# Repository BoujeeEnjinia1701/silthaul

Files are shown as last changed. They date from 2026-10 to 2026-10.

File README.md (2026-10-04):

# SiltHaul

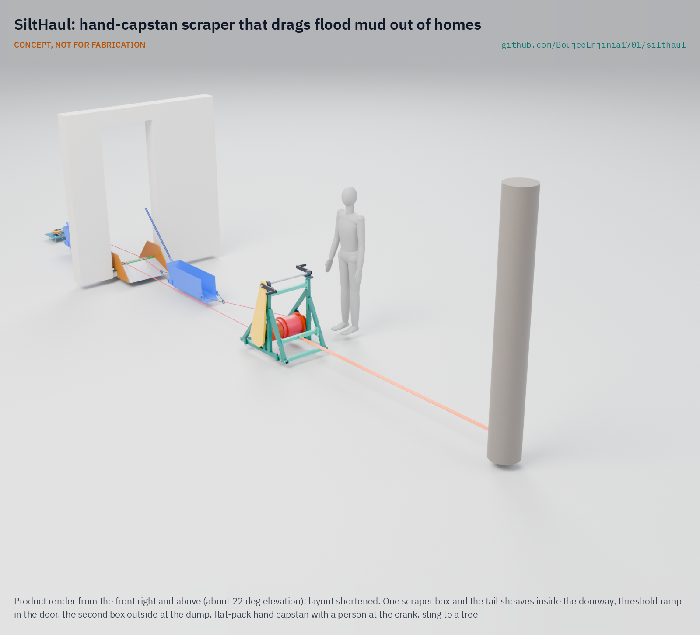
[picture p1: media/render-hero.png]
SiltHaul: hand-capstan scraper that drags flood mud out of homes


     

**Area:** Situational field hardware · **TRL:** 3 of 9 (proof of concept on paper; constructable design) · **Value-engineering target:** USD 2,000; estimated parts cost USD 887.50 · **Difficulty:** 3 of 5

Drags flood mud out of homes, lanes and drains with a hand-capstan scraper instead of shovels and buckets.

> CONCEPT, NOT FOR FABRICATION. SiltHaul is a TRL 3 design on paper: it has not been built or tested.

## Concept rationale

Mines solved a similar job a century ago with the slusher: a scraper dragged across the floor by rope and returned by a tail rope through a sheave at the far end ([Mining History Association](https://www.mininghistoryassociation.org/Journal/MHJ-v22-2015-Reynolds.pdf)). SiltHaul is a hand-powered slusher for flooded homes. A hand capstan is anchored outside the door, a tail sheave is fixed inside the room, and a rope loop runs between them to a scraper box. Crank one way and the box drags a load of mud out through the door; crank the other way and it returns for the next.

The point is to change who carries the weight. With shovels and buckets, people lift and carry every kilogram of mud. With SiltHaul, they load the box where it sits and the rope does the carrying. It uses no fuel and no power, fits through a doorway and packs into a car, so community groups and relief teams can bring it into lanes that machines cannot reach.

## Burning platform

After the 2018 Kerala floods, about 70,000 people joined a single clean-up drive in Kuttanad, aiming to clean about 100,000 buildings of silt, debris and mud across 16 panchayats ([Gulf News, 2018](https://gulfnews.com/world/asia/india/kerala-flood-70000-people-participate-in-massive-post-flood-clean-up-drive-in-kuttanad-1.2271770)). In the weeks that followed, at least 66 people died of leptospirosis ([Quartz, 2018](https://qz.com/india/1377755/after-kerala-floods-leptospirosis-has-killed-nearly-70-in-india)), and the state health department told everyone engaged in cleaning after the flood to take preventive medicine ([Mongabay, 2018](https://india.mongabay.com/2018/09/leptospirosis-outbreak-causes-concern-in-kerala-after-the-floods/)).

The pattern repeats wherever floods reach homes. In Valencia in 2024, thousands of volunteers self-organised to clear mud and debris after floods that killed at least 232 people ([Wikipedia](https://en.wikipedia.org/wiki/2024_Spanish_floods)). OSHA warns that flood clean-up workers risk back, knee and shoulder injuries from manual lifting and handling, and faces biological hazards from sewage and other contamination in floodwater ([OSHA](https://www.osha.gov/flood/response)).

## Where it could be used

### By industry

| Industry | Use |
| --- | --- |
| Disaster relief and humanitarian response | Mud clearance kits for volunteer and NGO clean-up teams |
| Municipal services | Clearing silted drains, culverts and narrow lanes without heavy plant |
| Civil protection and volunteer fire services | Pre-positioned flood recovery equipment |
| Housing and restoration contractors | Mucking out ground floors and basements where machines cannot enter |
| Agriculture | Clearing silt from farm buildings, sheds and small channels after floods |

### By country or region

| Country or region | Why it matters there |
| --- | --- |
| India | About 70,000 volunteers turned out to clean about 100,000 buildings in Kuttanad after the 2018 Kerala floods ([Gulf News, 2018](https://gulfnews.com/world/asia/india/kerala-flood-70000-people-participate-in-massive-post-flood-clean-up-drive-in-kuttanad-1.2271770)). |
| Pakistan | The 2022 floods affected 33 million people and caused USD 5.6 billion of damage to housing ([ReliefWeb, PDNA](https://reliefweb.int/report/pakistan/pakistan-floods-2022-post-disaster-needs-assessment)). |
| Spain | After the 2024 Valencia floods, thousands of volunteers self-organised to clean mud and debris from affected towns ([Wikipedia](https://en.wikipedia.org/wiki/2024_Spanish_floods)). |
| Germany | In the Ahr valley in 2021, about 3,000 of 4,200 buildings along the river were damaged, and clean-up was still running six months later ([deutschland.de](https://www.deutschland.de/en/topic/environment/catastrophic-flooding-in-germany-rebuilding-in-the-ahr-valley)). |

## What sparked the idea

The idea came from the scale of the 2018 Kerala clean-up. In Kuttanad, about 70,000 people, from as far as Kannur district, came together to clear silt and mud from about 100,000 buildings, and ministers warned rehabilitation could take six months to a year ([Gulf News, 2018](https://gulfnews.com/world/asia/india/kerala-flood-70000-people-participate-in-massive-post-flood-clean-up-drive-in-kuttanad-1.2271770)). That much human effort, with shovels and buckets, suggested that a simple tool which moved mud by rope rather than by arms could multiply what each volunteer can do.

## Problem

After a flood, homes, lanes and drains are left full of heavy, contaminated mud, and it is cleared almost entirely by hand with shovels and buckets. The work is slow, exhausting and puts people in long contact with dirty water and silt.

Full problem statement: [docs/01-problem.md](docs/01-problem.md)

## Concept

A scraper box hauled on a rope loop by a hand capstan anchored outside, with a tail sheave inside the room; workers crank the capstan to drag flood mud out of homes, lanes and drains instead of shoveling it into buckets.

Full design precis: [docs/02-concept.md](docs/02-concept.md) · Requirements: [docs/03-requirements.md](docs/03-requirements.md) · Calculations: [docs/04-calcs/01-sizing.md](docs/04-calcs/01-sizing.md) · Prototype build plan: [docs/05-build-plan.md](docs/05-build-plan.md) · Design decisions: [docs/06-design-decisions.md](docs/06-design-decisions.md) · [3D viewer](media/viewer.html)

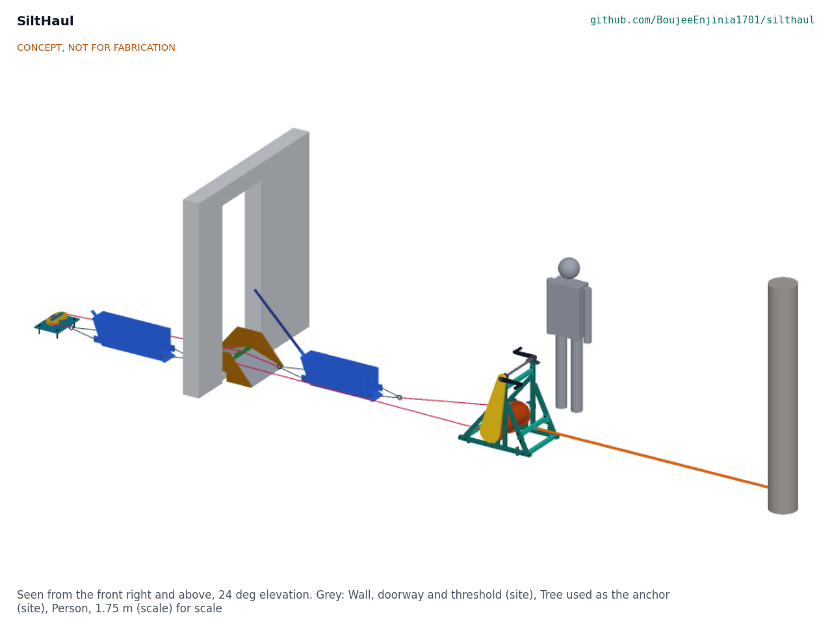
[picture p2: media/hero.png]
Concept: tail sheave block and box in the room, ramp in the doorway, hand capstan outside (layout shortened)


On paper (SLH-CAL-001): two boxes ride on the rope loop, so every stroke hauls a full 40 L box out while the other goes back to be filled. Two people at the cranks need 63 N each; a shear pin caps the rope tension at about 2.5 kN; the frame packs flat and the heaviest lift is 23.1 kg. It moves about 0.51 m³ an hour with a crew of four and a rest allowance, 0.57 times what the same crew moves with buckets, and nobody lifts or carries mud. Requirement R1, as Amish restated it (at least 0.5 times the bucket crew), is met on paper.

## Key components

- Hand capstan: a split winding drum, 4:1 chain drive, two cranks, shear pin and two ratchet wheels with pawls
- Outside anchor set: round sling to a tree or vehicle, four ground stakes
- Tail sheave block: two sheaves on a floor plate held by four M12 anchors
- Rope loop: 10 mm polyester pull rope and return rope
- Two scraper boxes: 210 mm wide, 40 L each, one on each rope, open toward the door, with bridles and a shared tipping bar
- Doorway rope guard: threshold ramp with a crest roller
- Stop signal and briefing card

## Building the prototype

The build plan takes a capable maker from stock steel tube, plate and sheet to a working prototype in thirteen illustrated steps, with a making sketch for each made part and close-ups of every joint that needs one. The flat-pack capstan frame, drum, two boxes, tail plate and ramp are welded or bolted from stock; the bearings, sprockets, chain, sheaves, anchors, rope and lifting gear are bought. It is a plan, not yet built; building and testing to it is TRL 4 work. See [docs/05-build-plan.md](docs/05-build-plan.md).

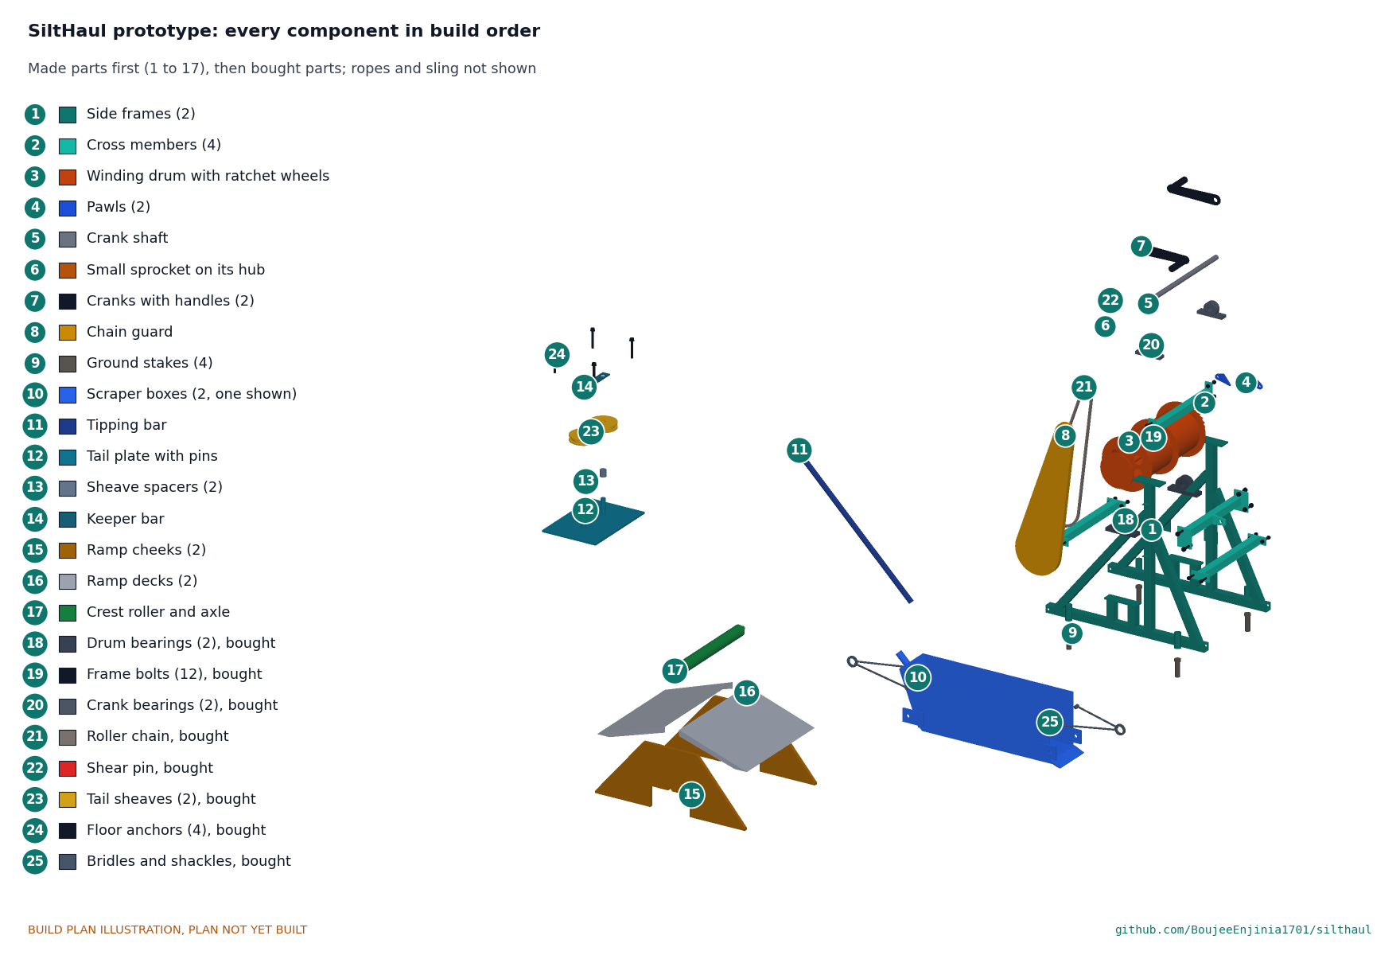
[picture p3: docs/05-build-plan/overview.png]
Every component of the prototype, pulled apart and numbered in build order


## Safety

> Published as an open engineering reference, not certified equipment. Users are responsible for their own risk assessment.
>
> This is a rope-and-anchor system under tension: a failed anchor or rope can whip. Nobody stands in the line of the rope or beside the sheave while cranking.
>
> All anchors, sheaves and ropes must be proof-loaded before use and inspected each day.
>
> The chain drive is fully guarded and a 4 mm shear pin limits the rope tension; never run without the guard or replace the pin with a stronger one. Choose a pawl before letting go of the cranks; two people tip the box, only with a pawl holding.
>
> The tail sheave block is anchored only to a sound concrete slab, never to walls or door frames; the capstan sling runs level or rises 10 degrees at most.
>
> Check the building for structural damage and switch off electricity before work starts.
>
> Flood mud may carry sewage and disease; users need boots, gloves and hygiene measures, and should follow local health advice.
>
> This design is published as an open engineering reference. It is not certified equipment. TRL 3 concept, not released for fabrication.

## Repository layout

| Folder | Contents |
| --- | --- |
| `docs/` | Problem, concept, requirements, calculations and design decisions |
| `cad/src/` | build123d Python source, the source of truth for all geometry |
| `cad/step/`, `cad/stl/` | Exported models for FreeCAD, other CAD tools and printing |
| `cad/drawings/` | 2D sketches and dimensioned drawings |
| `bom/` | Bill of materials |
| `electronics/` | KiCad schematics and PCB layouts |
| `firmware/` | Microcontroller code |
| `media/` | Renders, perspectives and photos |
| `build-log/` | Dated prototyping notes |

## Documentation

Controlled documents follow the portfolio [documentation standard](.kit/STANDARDS.md). Each carries a document ID (SLH-PRC-001 for the precis), a version and a revision history. Branded PDFs are built with `python .kit/render.py` and attached to GitHub Releases when a document is tagged, for example `SLH-PRC-001/v1.0`.

## Credits

Designed by Amish Chadha at Design Molecule Labs. See [CONTRIBUTORS.md](CONTRIBUTORS.md) for roles. To cite this design, use [CITATION.cff](CITATION.cff) (GitHub shows it as "Cite this repository").

AI assistance (Claude) was used to accelerate prototype documentation and first-pass research. Design direction and all decisions are Amish Chadha's, recorded in this repository's decision records (`docs/decisions/`).

## Licenses

- **Hardware** (CAD, drawings, BOM, electronics): [CERN-OHL-S v2](LICENSE)
- **Software** (firmware, scripts, notebooks): [MIT](LICENSE-SOFTWARE)

A project of the [Design Molecule](https://designmolecule.com) lab.

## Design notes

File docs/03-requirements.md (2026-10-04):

---
doc_id: SLH-REQ-001
title: SiltHaul requirements
project: SiltHaul
doc_type: Requirements
version: "0.5"
status: Draft
date: '2026-10-03'
author: Amish Chadha
license: CERN-OHL-S-2.0
revisions:
- version: "0.1"
  date: '2026-09-30'
  author: Amish Chadha
  change: Initial scaffold
- version: "0.2"
  date: '2026-10-03'
  author: Amish Chadha
  change: TRL 2 requirements with concept status; R11 overload limit and R12 load holding added (SLH-DDR-001)
- version: "0.3"
  date: '2026-10-03'
  author: Amish Chadha
  change: TRL 3 status from SLH-CAL-001 on the constructable design (SLH-DDR-002); R10 restated against the value-engineering target
- version: "0.4"
  date: '2026-10-03'
  author: Amish Chadha
  change: Amish's requirement decisions (SLH-DDR-003); R1 restated (no lifting or carrying of mud; at least 0.5 times the bucket crew) and met on paper with a second box on the return leg; R9 met on paper with a flat-pack frame; status rerun from SLH-CAL-001 v0.3
- version: "0.5"
  date: '2026-10-03'
  author: Amish Chadha
  change: "Amish's round-2 decision 2A (SLH-DDR-004): R9 restated as \"fits a small hatchback with the rear seats folded; heaviest part 25 kg or less\" and accepted as met on paper"
---

# SiltHaul requirements

Eleven of the twelve requirements are met on paper or by design, one (R8, setup time, now estimated at the 20 min limit) can only be verified by a timed trial, and none is reported not met (SLH-CAL-001 v0.4, Table 3). In round 2 (2026-10-03) Amish agreed with the recommendation on R9 (2A of SLH-DDR-004): "i agree with all the 46 recommendations you provided. please proceed." R9 is restated as "fits a small hatchback with the rear seats folded; heaviest part 25 kg or less". On 2026-10-03 Amish chose option A on every requirement decision put to him ("1A 2A 3A 4A 5A 6A 7A 8A 9A 10A 11A"), which for SiltHaul meant two changes (SLH-DDR-003). Under 2A, R1 is restated as "no lifting or carrying of mud; output at least 0.5 times the same crew with shovels and buckets", and a second box rides on the return leg so the rope loop carries mud out on both strokes: about 0.51 m³ an hour with rest, a ratio of 0.57. Under 7A, the frame is a bolted flat-pack frame so the kit fits a small car boot, with the 25 kg heaviest-part limit kept. R11 and R12 were added at TRL 2 under Amish's pre-approval of 2026-10-03 (SLH-DDR-001), because the anchors and rope can only be sized on a known maximum rope tension, and a hand-cranked load must hold when the handles are let go. "Met on paper" means shown by calculation, not by test.

> **Safety:** SiltHaul is a rope-and-anchor system under tension with a hand-cranked chain drive. R6, R7, R11 and R12 are its safety requirements; they are checked on paper only and must be proved by proof-load tests before anyone uses the kit (SLH-BLD-001, section 6).

Table 1. Requirements and status at TRL 3

| ID | Requirement | Target | Verification (TRL 3 or later) | Status (SLH-CAL-001) |
| --- | --- | --- | --- | --- |
| R1 | Mud moved per hour by a crew of four | No lifting or carrying of mud; output at least 0.5 times that of the same crew with shovels and buckets (estimate) | Side-by-side timed trial on a test bed of wet silt | Met on paper: 0.51 against 0.90 m³/h (ratio 0.57); loaders push mud in over the lip; nobody lifts or carries it |
| R2 | Crank handle force at full box | 150 N (34 lbf) or less per person with two people at the cranks | Spring balance at the handle during trial | Met on paper: 63 N each at 1,000 N (126 N for one person); 61 N each at the 970 N stroke estimate |
| R3 | Scraper box capacity | About 40 L (10 US gal) of wet mud per trip | Measured fill on test bed | Met by design: 40.3 L in each of the two boxes at a 245 mm fill |
| R4 | Fits through a doorway | Box, tail block and ramp pass a 0.7 m (28 in) opening, with the return leg beside the box | Fit test | Met by design: each box 258 mm over the shackles; the boxes pass 42 mm apart and cross the ramp 26 mm inside its cheeks; ramp 646 mm |
| R5 | Working length | Up to 15 m (49 ft) from tail sheave to capstan | Trial at full length | Met by design: 12 m of travel on each drum half; capstan at least 6 m from the door |
| R6 | Rope and anchor strength | Minimum break strength at least 5 times the working pull, and at least 5 times the R11 limit for the rope and chain | CalRig proof-load test of each anchor type | Met on paper: rope 18 times working, 5.4 at the limit; chain 5.0 |
| R7 | Tail anchor independent of walls | Holds the R11 limit on both legs on a bare concrete floor with no wall contact | Pull test on the anchored tail block | Met on paper on a sound slab: 0.45 of recommended anchor loads |
| R8 | Setup time | Three people set up in 20 min or less | Timed trial | Not verifiable at TRL 3: about 20 min estimated, at the limit (bolting the frame and shackling two boxes add 4 min) |
| R9 | Portability | Kit fits a small hatchback with the rear seats folded; heaviest part 25 kg or less (25 kg is 55 lb) | Weigh and pack test | Met on paper, as restated by Amish (2A, round 2): heaviest lift 23.1 kg (drum with bearings); flat-pack frame, largest piece 890 x 814 x 83 mm; kit about 454 L packed against a 594 L small car boot |
| R10 | Cost | Prototype parts at or under the USD 2,000 value-engineering target (a hypothetical control target) | Costed bill of materials | Met on paper, within the target: USD 1,055.60 (USD 944.40 under) |
| R11 | Overload limit | Rope tension limited to 3,000 N whatever force the crew applies | Shear pin release test on the capstan | Met on paper: shear pin releases at 2,451 N (1,961 to 2,941 N) |
| R12 | Holds when let go | The drum holds the load in either direction when the cranks are released | Release test at working pull | Met by design: two ratchet wheels and pawls on the drum shaft |

## Requirements at risk or not met

None is reported not met. Two results are close to their limits and are watched at TRL 4:

- **R1.** The ratio of 0.57 rests on estimated loading, dumping and bucket rates; a timed trial settles it. The restatement is Amish's (2A, 2026-10-03): "no lifting or carrying of mud; output at least 0.5 times the same crew with shovels and buckets".
- **R8.** About 20 min with three people, at the limit, now that the frame is bolted together on site and two boxes are shackled.
- **R9.** Accepted by Amish with the rear seats folded (round 2, 2A, 2026-10-03: "i agree with all the 46 recommendations you provided. please proceed."), and restated as "fits a small hatchback with the rear seats folded; heaviest part 25 kg or less". With the seats up the 890 x 814 mm side frames do not lie flat in a typical small boot; that is no longer an open question.

## Assumptions

- Most flood mud is fluid enough to be scraped and dragged, not dug; very stiff or deep deposits may still need shovels first.
- The building has a sound concrete slab at least 100 mm thick for the tail block anchors; where it does not, SiltHaul is not used in that room.
- Volunteers accept a short briefing on rope safety.
- "A small hatchback with the rear seats folded" is taken as a small hatchback's load space with the rear seats folded: 1,250 mm long, 950 mm wide and 500 mm high (about 594 L).
- Loaders push or rake mud into the box over its lip at floor level; the box is 305 mm tall, so shovelling over the side is possible but not needed.
- A safe dump point exists outside within rope reach, and an anchor point (a sound tree or a parked vehicle) exists behind the capstan.

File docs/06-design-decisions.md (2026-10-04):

---
doc_id: SLH-DEC-001
title: SiltHaul design decisions register
project: SiltHaul
doc_type: Design decisions register
version: "0.3"
status: Draft
date: '2026-10-03'
author: Amish Chadha
license: CERN-OHL-S-2.0
revisions:
- version: "0.1"
  date: '2026-10-03'
  author: Amish Chadha
  change: Register opened; every decision made under Amish's pre-approval of 2026-10-03
- version: "0.2"
  date: '2026-10-03'
  author: Amish Chadha
  change: Amish's requirement decisions 2A and 7A recorded (SLH-DDR-003); boot reading for R9 opened for Amish
- version: "0.3"
  date: '2026-10-03'
  author: Amish Chadha
  change: "Open decision 1 decided (round 2, 2A) and recorded as SLH-DDR-004; no open decisions"
---

# SiltHaul design decisions register

Every design decision still to be made, and every decision made, in one place. Each decision is argued in full in its decision record under `docs/decisions/`; this register is the index Amish works from. The build plan (`docs/05-build-plan.md`) describes the design as it stands and does not list decisions.

> **Safety:** Several decisions below set SiltHaul's safety case (overload limit, holding, anchors, dumping). Each took the conservative option; the evidence that would relax it is in SLH-DDR-001, Table 1.

## Open decisions

None. Open decision 1 (what "fits a small car boot" means) was decided by Amish on 2026-10-03: the rear seats folded; see Decisions made and SLH-DDR-004.

## To confirm when parts are bought

| # | What to confirm | Why it matters | Source |
| --- | --- | --- | --- |
| 1 | Release load of the shear pins from the bar actually bought | The 4 mm pin is sized on 240 MPa shear; a stronger bar raises the overload limit above 3,000 N | SLH-CAL-001, F; R11 |
| 2 | Recommended loads of the M12 wedge anchor bought, in the concrete grade expected | The tail block check uses 4 kN tension and 6 kN shear | SLH-CAL-001, I; R7 |
| 3 | Rope breaking strength and splice efficiency of the rope bought | Factor 5.4 at the limit assumes 18 kN and 90 % at the splice | SLH-CAL-001, G; R6 |
| 4 | Sheave bore and rating | Pins are 25 mm; the sheaves must be rated at least 1,000 kg | BOM line 14 |
| 5 | Bearing centre heights and bolt pitches | The pads and top plates are drilled to UCP206 and UCP205 catalogue sizes | SLH-DWG-101 |
| 6 | Sprocket bores and the 12-tooth sprocket's fit on the 36 mm hub | Sets the hub and the line-up with the 48-tooth wheel | SLH-DWG-104 |

## Value engineering

Value-engineering target: USD 2,000 (a hypothetical control target, not a limit). Estimated cost of the constructable design: USD 1,055.60 (USD 944.40 under the target). Main cost drivers and savings worth trying:

- The two boxes (USD 160) and the winding drum (USD 98) are the largest made parts; the rope (USD 80.60), the ramp (USD 73) and the frame (USD 72) follow.
- Bought lifting gear (sling, shackles, two bridle sets, USD 164) is kept at rated, traceable grades because it carries the safety case.
- Savings worth trying: a drum from a scrap gas cylinder or pipe offcut of the same diameter; a timber ramp with a steel wear strip; buying rope with factory eye splices in bulk.

## Decisions made

| Date | Decision | Decided by | Record |
| --- | --- | --- | --- |
| 2026-10-03 | Split winding drum in place of a friction capstan; 4:1 chain drive with two cranks | Amish: "I pre-approve the batch runs along with any recommendations you come up with." | SLH-DDR-001, items 1, 2 |
| 2026-10-03 | Shear pin limits rope tension to about 2.5 kN; all parts sized on 3,000 N; requirement R11 added | Amish: "I pre-approve the batch runs along with any recommendations you come up with." | SLH-DDR-001, item 3 |
| 2026-10-03 | Two opposite ratchet wheels and pawls on the drum shaft; requirement R12 added | Amish: "I pre-approve the batch runs along with any recommendations you come up with." | SLH-DDR-001, item 4 |
| 2026-10-03 | Tail block on four drilled floor anchors only, never walls or door frames | Amish: "I pre-approve the batch runs along with any recommendations you come up with." | SLH-DDR-001, item 5 |
| 2026-10-03 | Capstan anchored by a round sling to a tree or vehicle, level or rising 10 degrees at most; stakes only against skating | Amish: "I pre-approve the batch runs along with any recommendations you come up with." | SLH-DDR-001, item 6 |
| 2026-10-03 | 10 mm polyester double braid, 18 kN | Amish: "I pre-approve the batch runs along with any recommendations you come up with." | SLH-DDR-001, item 7 |
| 2026-10-03 | Box open toward the door, sloped back, forward tipping; two people on the tipping bar | Amish: "I pre-approve the batch runs along with any recommendations you come up with." | SLH-DDR-001, items 8, 9 |
| 2026-10-03 | Capstan at least 6 m beyond the door | Amish: "I pre-approve the batch runs along with any recommendations you come up with." | SLH-DDR-001, item 10 |
| 2026-10-03 | First co-design candidate to approach: Kerala State Disaster Management Authority (not agreed) | Amish: "I pre-approve the batch runs along with any recommendations you come up with." | SLH-DDR-001, item 11 |
| 2026-10-03 | SiltHaul capstan recorded as the candidate common block for SaltDrag; CalRig as the first candidate proof-load rig | Amish: "I pre-approve the batch runs along with any recommendations you come up with." | SLH-DDR-001, item 12 |
| 2026-10-03 | `budget_usd` kept at 2,000 as a value-engineering target | Amish: "I also accept any cost overruns or variations from the assumed scope cost." | SLH-DDR-001, item 13 |
| 2026-10-03 | R1 kept as the trial target and reported not met on paper (superseded by 2A below) | Amish: "I pre-approve the batch runs along with any recommendations you come up with." | SLH-DDR-001, Consequences |
| 2026-10-03 | Design for construction: the thirteen changes of SLH-DDR-002 | Amish: "I pre-approve the batch runs along with any recommendations you come up with." | SLH-DDR-002 |
| 2026-10-03 | Appearance model additions for renders: wound rope on the drum, stakes above ground only, context wall, tree and mannequin | Amish: "I pre-approve the batch runs along with any recommendations you come up with." | docs/REVIEW.md, TRL 3 |
| 2026-10-03 | 2A: second box on the return leg so the rope loop carries mud both ways; R1 restated as "no lifting or carrying of mud; output at least 0.5 times the same crew with shovels and buckets" (now 0.57, met on paper) | Amish: "1A 2A 3A 4A 5A 6A 7A 8A 9A 10A 11A" | SLH-DDR-003, items 1 to 5 |
| 2026-10-03 | 7A: bolted flat-pack frame (two welded side frames, four bolted cross members) that fits a small car boot, keeping the 25 kg heaviest-part limit (heaviest lift 23.1 kg) | Amish: "1A 2A 3A 4A 5A 6A 7A 8A 9A 10A 11A" | SLH-DDR-003, items 6 to 8 |
| 2026-10-03 | 2A (round 2): R9 accepted with the rear seats folded and restated as "fits a small hatchback with the rear seats folded; heaviest part 25 kg or less"; met on paper (heaviest lift 23.1 kg; kit about 454 L in 594 L). No design change | Amish: "i agree with all the 46 recommendations you provided. please proceed." | SLH-DDR-004 |

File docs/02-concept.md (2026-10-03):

---
doc_id: SLH-PRC-001
title: SiltHaul design precis
project: SiltHaul
doc_type: Precis
version: "0.3"
status: Draft
date: '2026-10-03'
author: Amish Chadha
license: CERN-OHL-S-2.0
revisions:
- version: "0.1"
  date: '2026-09-30'
  author: Amish Chadha
  change: Initial scaffold
- version: "0.2"
  date: '2026-10-03'
  author: Amish Chadha
  change: TRL 2 precis; how it works, components, first-order numbers, key design choices (SLH-DDR-001), safety
- version: "0.3"
  date: '2026-10-03'
  author: Amish Chadha
  change: TRL 3 figures from SLH-CAL-001 and the constructable design (SLH-DDR-002); split winding drum, shear pin, two-sheave tail block, ramp
---

# SiltHaul design precis

Drags flood mud out of homes, lanes and drains with a hand-capstan scraper instead of shovels and buckets.

Figure 1. SiltHaul in use, layout shortened

*Figure 1. Concept render: tail sheave block and scraper box in the room, ramp in the doorway, hand capstan outside with a sling to a tree (layout shortened).*

## Summary

SiltHaul is a hand-powered slusher for flooded buildings. Two steel scraper boxes, each 210 mm wide and holding about 40 L, are tied into a rope loop that runs from a hand capstan outside, through the doorway, round a tail sheave block anchored to the floor at the far end of the room, and back. Cranking one way drags one loaded box out through the door to a dump point while the other comes back empty; cranking the other way swaps them, so mud goes out on every stroke (SLH-DDR-003). Two people at the cranks need 63 N each; nobody lifts or carries mud out of the building. The design is constructable, its frame packs flat, its parts cost about USD 1,056 against a USD 2,000 value-engineering target, and its heaviest lift is 23.1 kg. On paper it moves about 0.51 m³ an hour with a crew of four and a rest allowance, 0.57 times a bucket crew (SLH-CAL-001).

## How it works

1. **Set up.** The capstan stands outside, at least 6 m beyond the door and in line with it, held back by a round sling to a tree or a parked vehicle and kept from skating by four stakes. The tail sheave block is bolted to the concrete floor at the far end of the room with four M12 anchors. A ramp straddles the threshold.
2. **The loop.** The pull rope runs from the lower side of the drum's pull half, over the ramp roller, to the box's front bridle. The return rope runs from the box's rear bridle to the tail block, round its two sheaves and back beside the box, 300 mm to one side, over the ramp roller to the top of the drum's return half.
3. **Haul.** Cranking winds the pull rope onto one half of the drum while the other half pays out the return rope at the same rate, so the loop stays the same length. The box's open front, which faces the door, scoops mud as it goes; workers also shovel or push mud into it.
4. **Dump.** The box stops at a dump point outside. A pawl holds the drum. Two people lift the loose tipping bar, which drops into a socket on the back, and the box rolls forward over its lip and empties.
5. **Return.** The other pawl is chosen and the cranks turned the other way. The sloped back rides over the mud as the empty box is pulled back.

## Main components

*Table 1. Components (numbers are BOM lines).*

| # | Component | What it is |
| --- | --- | --- |
| 1 | Capstan frame | Flat-pack, 40 mm square tube: two welded side frames (890 x 814 mm, 9.2 and 9.6 kg) with bearing pads, stake tubes and pawl brackets, joined by four bolted cross members including an anchor bar and eye at drum height |
| 2 | Winding drum | 219.1 mm tube in two halves of 21 turns each, on a 30 mm shaft, with a 48-tooth sprocket and two opposite ratchet wheels; 19.0 kg |
| 3, 4 | Bearings | UCP206 pillow blocks for the drum, UCP205 for the crank shaft |
| 5 | Crank shaft and cranks | 25 mm shaft 850 mm up, two 250 mm cranks set 180 degrees apart |
| 6, 7 | Chain drive | ISO 08B-1 chain, 12 to 48 teeth, 4:1 |
| 8 | Pawls | Two, one for each direction |
| 9 | Chain guard | Closed 1.5 mm sheet guard round the chain and sprockets |
| 10 | Shear pin | 4 mm S235 pin in the small sprocket hub; limits rope tension to about 2.5 kN |
| 11, 12 | Outside anchor set | Four stakes and a 2,000 kg round sling with shackles |
| 13 to 15 | Tail sheave block | 10 mm floor plate with two 125 mm sheaves on 25 mm pins, a keeper bar and four M12 floor anchors |
| 16 | Ropes | 10 mm polyester double braid, 18 kN: a 17 m pull rope and a 38 m return rope |
| 17, 18, 20 | Scraper box | 2 mm steel box with a bevelled lip, skids, sloped back, bridle lugs, bridles and a loose tipping bar |
| 19 | Doorway ramp | Plywood cheeks, steel decks and a crest roller; fits 0.7 m doors and 110 mm thresholds |
| 22 | Stop signal and briefing card | Hand signals, whistles and the stop rule |

## Numbers from the TRL 3 calculations

*Table 2. Key figures (SLH-CAL-001).*

| Quantity | Value |
| --- | --- |
| Full box | 40.3 L, 86 kg with mud at 1.7 kg/L; two boxes |
| Haul pull | 970 N estimated for a full box out and the empty one back; 1,000 N working pull |
| Crank force | 63 N each with two people; 126 N for one |
| Rope speed | 5.4 m/min |
| Stroke over 11 m | 3.54 min; 17 strokes and 0.68 m³ an hour (0.51 with rest) |
| Overload limit | Shear pin releases at about 2,450 N; all parts sized on 3,000 N |
| Rope | Factor 18 on the working pull, 5.4 on the limit |
| Tail block | 0.45 of recommended anchor loads at the limit |
| Heaviest lift | Drum with bearings 23.1 kg; box 16.1 kg |
| Cost | Value-engineering target: USD 2,000. Estimated cost of the constructable design: USD 1,055.60 (USD 944.40 under the target) |

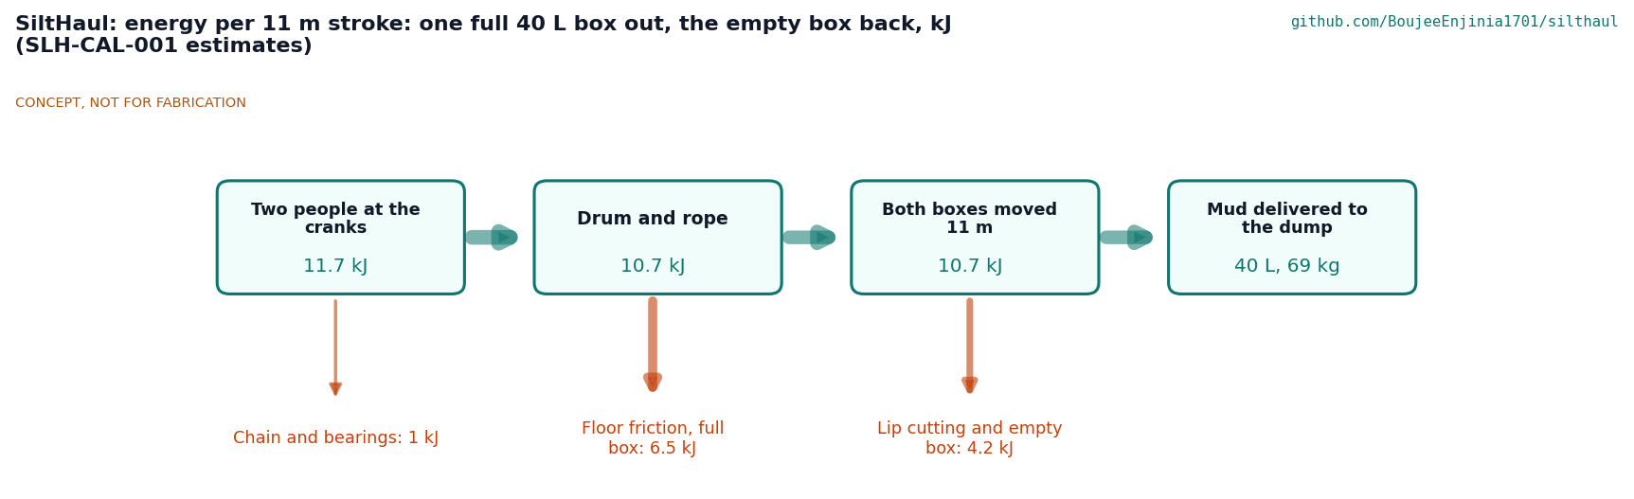
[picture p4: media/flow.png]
Figure 2. Energy per haul


*Figure 2. Energy for one 11 m haul of a full box (estimates): most of what the crank crew puts in goes to dragging the box over the floor.*

## Key design choices

All decided on 2026-10-03 under Amish's pre-approval (SLH-DDR-001 and SLH-DDR-002):

- **Split winding drum, not a friction capstan.** A loop on a friction drum needs a pretension of about half the pull and its turns walk along the drum. A drum whose halves wind and unwind together cannot slip and keeps the loop length constant.
- **Overload limit by shear pin.** Without it a jammed box and two people heaving could put 6.4 kN into the rope. With it every part is sized on 3,000 N.
- **Two ratchet wheels on the drum shaft.** The drum is held in either direction, even if the chain or pin fails.
- **A box on each leg.** Two boxes 210 mm wide on lines 300 mm apart pass each other in the room and both cross the ramp in a 0.7 m door, so mud goes out on every stroke (SLH-DDR-003).
- **Open front facing the door.** The box scoops on the way out and keeps its load against its back; it tips forward over its lip at the dump, like a Fresno scraper.
- **Tail block on drilled floor anchors only.** No reliance on walls or door frames; a room without a sound slab is not worked with SiltHaul.
- **Sling at drum height.** The anchor eye is 200 mm up so the rope and the sling pull in line and the capstan cannot tip.

## Patent design-arounds

From the preliminary patent, trademark and prior-art screen (not legal advice):

- Slusher patents US2588657A and US3532170A have expired and are free prior art; the Fresno scraper's forward-tipping bowl is nineteenth-century prior art.
- WO2017216731A1 (Sulzer scraper winch) is shown as ceased on Google Patents; a South African family member (ZA201808475B) is listed and should be confirmed before release. SiltHaul uses a hand-cranked split drum, not motor-driven drums.
- Watch item from the preliminary screen: tail-sheave anchor on weak, wet walls. The tail block has its own floor anchors and never bears on a wall.

## Relationship to other lab projects

- **Hand capstan common block.** SiltHaul's capstan is recorded as the candidate common block for SaltDrag; SaltDrag is checked against it when it reaches TRL 3 (not edited here).
- **CalRig.** The first candidate rig for the proof loads of the anchors, rope and capstan.

## Safety

> **Safety:** Published as an open engineering reference, not certified equipment. Users are responsible for their own risk assessment.
>
> **Rope under tension.** A failed anchor, shackle or rope can whip. Nobody stands in the line of a rope, inside the loop, or beside a sheave or the ramp while the cranks turn. The shear pin limits rope tension to about 2.5 kN; never replace it with a stronger pin or a bolt.
>
> **Moving machinery.** The chain and sprockets are fully guarded; never turn the cranks with the guard off. Keep hands clear of the drum and rope where it winds on. Choose the pawl before letting go of the cranks.
>
> **Anchors.** Every anchor, the rope and the capstan are proof-loaded before first use and the rope, splices, shackles and anchors are inspected each day. The tail block is used only on a sound concrete slab; the sling runs level or rises 10 degrees at most.
>
> **Dumping.** Two people lift the tipping bar, only when the cranks are stopped and a pawl is holding.
>
> **The building and the mud.** Check the building for structural damage and switch off electricity before work starts. Flood mud may carry sewage and disease; users need boots, gloves and hygiene measures, and should follow local health advice.
>
> **Stop rule.** One signaller, a whistle and the card's hand signals. One blast stops the cranks; nobody enters the rope area until the signaller says so.

## Open questions

None for the design. Questions about mud, floors and people are for the first trials: how the box fills and drags in liquid slurry and stiff clay, how often the slab is sound enough for the tail anchors, and the real bucket-crew rate for R1.

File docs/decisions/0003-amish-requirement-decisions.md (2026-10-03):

---
doc_id: SLH-DDR-003
title: SiltHaul second box on the return leg and flat-pack frame
project: SiltHaul
doc_type: Design decision record
version: "0.1"
status: Draft
date: '2026-10-03'
author: Amish Chadha
license: CERN-OHL-S-2.0
revisions:
- version: "0.1"
  date: '2026-10-03'
  author: Amish Chadha
  change: Amish's requirement decisions 2A (R1) and 7A (R9) carried into the constructable design
---

# 0003: Second box on the return leg and flat-pack frame

- **Date:** 2026-10-03
- **Status:** accepted

## Context

At TRL 3 (SLH-CAL-001 v0.2) SiltHaul missed R1, output, by a wide margin (0.32 m³ an hour, a ratio of 0.36 to a bucket crew against a target of 2), and R9, portability, was at risk because the welded frame, 890 x 663 x 814 mm, needed an estate car or small pickup. Both fixes change what the product is, so they were put to Amish as requirement decisions. On 2026-10-03 Amish chose option A on every decision put to him: "1A 2A 3A 4A 5A 6A 7A 8A 9A 10A 11A". For SiltHaul:

- **2A (R1).** Add a second box on the return run so the rope loop carries mud both ways; restate R1 as "no lifting or carrying of mud; output at least 0.5 times the same crew with shovels and buckets".
- **7A (R9).** Redesign the frame as a bolted flat-pack frame that fits a small car boot, keeping the 25 kg heaviest-part limit.

## Options considered

For 2A the open question was how two boxes fit through a 0.7 m door (R4) with their rope lines 300 mm apart, the spacing the drum and ramp already set.

| Option | Result | Chosen |
| --- | --- | --- |
| Two 446 mm boxes, lines moved about 540 mm apart | Ramp and door about 1.1 m wide; breaks R4 | No |
| Two narrow boxes on the existing 300 mm lines | 210 mm inside, 845 mm long, 280 mm sides: 40.3 L each; they pass 42 mm apart and cross the ramp 26 mm inside its cheeks | Yes |

For 7A the frame could come apart into two welded side frames joined by bolted cross members, or into loose tubes (rails, posts and braces each bolted). The side frames need only twelve bolts and keep every welded joint that carries the drum and crank bearings; loose tubes would fit a boot with the seats up but need about forty bolts and would push setup well past 20 min (R8).

## Decision

*Table 1. Changes made.*

| # | Part | Change | Result (SLH-CAL-001 v0.3) |
| --- | --- | --- | --- |
| 1 | Scraper boxes | Two identical boxes, 210 mm wide inside, 845 mm to the lip, 280 mm sides, back sloping 110 mm; box 1 on the pull rope, box 2 on the return rope, both open toward the door | 40.3 L each at a 245 mm fill (R3); 16.1 kg each |
| 2 | Ropes | Pull rope 17 m to box 1; return rope 17 m to box 2; a tail rope joins the two boxes' rear bridles round the tail sheaves, chosen for the room from 12.5, 9 and 6 m | 62 m of rope in all |
| 3 | Operation | Each stroke hauls one full box out while the other goes back empty; loaders fill one box while the crank crew dump the other | 3.54 min a stroke; 0.68 m³/h, 0.51 with rest; ratio 0.57 (R1 met on paper) |
| 4 | Ramp | Centred midway between the two box lines | Both boxes 26 mm inside the cheeks (R4) |
| 5 | R1 | Restated in Amish's words above | Met on paper |
| 6 | Capstan frame | Two welded side frames (rail, posts, braces, pads, top plate, stake tubes) and four bolted cross members (front and rear cross rails, top tie, anchor bar with eye), each with 8 mm end plates; eight M10 and four M12 bolts | Side frames 9.2 and 9.6 kg; cross members 8.0 kg in all |
| 7 | Stake tubes | Moved to 280 mm in front of and 330 mm behind the drum axis to clear the bolts | Stakes unchanged |
| 8 | R9 | Requirement unchanged; small car boot taken as a small hatchback with the rear seats folded (1,250 x 950 x 500 mm) | Heaviest lift 23.1 kg; kit about 454 L, 77 % of the boot (R9 met on paper) |

## Consequences

- `cad/src/model.py` adds box 2, its bridles, the tail rope and the bolted frame, with checks that the boxes pass with at least 25 mm between them, that both cross the ramp at least 15 mm inside the cheeks, and that every cross member and bolt touches the side frames. STEP and STL, SLH-DWG-001 and 002 (Rev P3), the concept media and the build plan pictures are regenerated.
- The working pull stays 1,000 N: the narrower lip cuts less mud, so a full box out and an empty box back need about 970 N. Handle force, rope, chain, shear pin and anchors are unchanged.
- Setup rises to about 20 min with three people, at the R8 limit.
- Value-engineering target: USD 2,000. Estimated cost of the constructable design: USD 1,055.60 (USD 944.40 under the target), up USD 168.10.
- Boxes pass 42 mm apart in the room: loaders keep hands and feet out from between them while the cranks turn.
- New open decision for Amish: whether "fits a small car boot" may assume the rear seats are folded (design decisions register).

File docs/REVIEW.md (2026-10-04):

# Review note: SiltHaul

## 2026-10-03: Amish's round-2 requirement decisions carried out

Amish, 2026-10-03: "i agree with all the 46 recommendations you provided. please proceed." For SiltHaul this is decision 2A on R9, recorded in `docs/decisions/0004-r9-rear-seats-folded.md` (SLH-DDR-004) and in the register `docs/06-design-decisions.md` (SLH-DEC-001 v0.3). A records and wording change only: no geometry, bill of materials, drawings or pictures changed.

| Change | Files | New result |
| --- | --- | --- |
| R9 accepted with the rear seats folded and restated as "fits a small hatchback with the rear seats folded; heaviest part 25 kg or less" | `docs/03-requirements.md` v0.5, `docs/04-calcs/01-sizing.md` v0.4 (wording), `docs/05-build-plan.md` v0.3 (pack check wording) | **R9 met on paper:** heaviest lift 23.1 kg against 25 kg; kit about 454 L packed against 594 L |
| Open decision 1 closed | `docs/06-design-decisions.md` v0.3, `docs/decisions/0004-r9-rear-seats-folded.md` | Open decisions: none |
| Cost | unchanged | Value-engineering target: USD 2,000. Estimated cost of the constructable design: USD 1,055.60 (USD 944.40 under the target). `budget_usd` unchanged |

Mass unchanged. Pictures changed: none. Appearance model unchanged, so the photoreal renders stand and no views were re-exported.

### Decisions proposed, awaiting Amish

None.

### Cross-repo actions

None.

### Safety

Packing the heavy parts into a car is a manual-handling task: no lift is above 25 kg and two people share the drum with bearings. The rope and anchor safety stops of the build plan are unchanged.

### Recommended next step

TRL 4 (proof loads, the shear pin test, the timed R1 and R8 trials and the pack test) needs a new instruction from Amish.

## 2026-10-03: Amish's requirement decisions carried out

Amish, 2026-10-03, on every requirement decision put to him: "1A 2A 3A 4A 5A 6A 7A 8A 9A 10A 11A". For SiltHaul that is 2A (R1) and 7A (R9), recorded in `docs/decisions/0003-amish-requirement-decisions.md` (SLH-DDR-003) and in `docs/06-design-decisions.md` (SLH-DEC-001 v0.2). No commit or push in this session; Amish pushes.

**Changes made and their new results (SLH-CAL-001 v0.3).**

- **2A, second box on the return leg (R1).** Two identical boxes, 210 mm wide inside, 845 mm to the lip, 280 mm sides (40.3 L each at a 245 mm fill, R3 met by design); box 1 on the pull rope, box 2 on the return rope, joined by a tail rope round the tail sheaves (12.5, 9 and 6 m tail ropes, chosen for the room). Each stroke hauls one full box out (752 N) and drags the empty one back (218 N): 970 N, inside the unchanged 1,000 N working pull, so R2 stays 63 N each. A stroke is 3.54 min; 0.68 m³/h, **0.51 m³/h with rest against 0.90 for buckets, ratio 0.57 against the restated 0.5: R1 met on paper** (was 0.36, not met). R1 restated in `docs/03-requirements.md` (v0.4) in Amish's words. The boxes pass 42 mm apart and cross the recentred ramp 26 mm inside its cheeks (R4 met by design). Tail block 636 N on either stroke; at the limit unchanged (0.45 of anchor loads).
- **7A, flat-pack frame (R9).** Two welded side frames (890 x 814 x 83 mm, 9.2 and 9.6 kg) and four bolted cross members with 8 mm end plates (front and rear cross rails, top tie, anchor bar with eye; 8.0 kg), eight M10 and four M12 bolts; stake tubes moved to 280 mm front and 330 mm rear to clear the bolts. Heaviest lift 23.1 kg (drum with bearings), within 25 kg. Kit packs into about 454 L, 77 % of a 594 L small hatchback boot with the rear seats folded: **R9 met on paper (rear seats folded)** (was at risk). Capstan 65.7 kg; sling-tipping check still holds (145 N m against 271 N m at 10 degrees).
- **R8** moves to about 20 min with three people, at the limit (bolting the frame and a second box add 4 min); still not verifiable at TRL 3.
- **R10.** Value-engineering target: USD 2,000. Estimated cost of the constructable design: USD 1,055.60 (USD 944.40 under the target), up USD 168.10: second box USD 80, second bridle set USD 54, rope 62 m (+USD 9.10), frame end plates and drilling USD 10, frame bolts USD 8, paint USD 5. Kit about 154 kg (was 132).
- Counts: 7 met on paper, 4 met by design, 1 not verifiable at TRL 3; none not met.

**Files.** `cad/src/model.py` (box 2, tail rope, bolted frame; new checks: boxes pass at least 25 mm apart, both at least 15 mm inside the ramp cheeks, cross members and bolts touch the side frames, pack pieces listed; no overlaps, no floating parts), STEP and STL regenerated; `bom/bom.csv` (lines 1, 16, 17, 18, 20, 21, 23); `docs/04-calcs/sizing.py`, `01-sizing.md` (v0.3), `results.csv`; `docs/03-requirements.md` (v0.4); `cad/src/sheets.py`, SLH-DWG-001 and 002 Rev P3; `cad/src/concept_media.py` (hero, exploded, flow, blueprint, model.glb); `cad/src/build_plan_media.py`: overview, SLH-DWG-101 (now side frames), new SLH-DWG-110 (cross members), SLH-DWG-107 (box), joints 04, 05 and new 09, steps 01 to 13 (new step 1, bolting the frame; step 13 reeves both boxes); `docs/05-build-plan.md` (v0.2, figures renumbered); `cad/src/product_model.py` (box 2, cross members and bolts in the views; scenes exported to `/home/claude/renders/silthaul`); headline figures in `README.md` and `docs/02-concept.md`.

**Open decision for Amish (register item 1).** What "fits a small car boot" means. With the seats up the 890 x 814 mm side frames do not lie flat in a typical 950 x 650 mm small-car boot floor. Options: A, accept the rear seats folded as the reference (R9 met on paper); B, split each side frame into bolted tubes, about forty bolts, setup well past 20 min. Recommendation: A.

**Safety.** The boxes pass 42 mm apart: nobody between them while the cranks turn (stop 4). The crank crew leave the cranks to dump, so a pawl must be holding first (stop 5). Tipping a full box now takes about 236 N on the longer box, shared by two people. Frame bolts must be checked tight before each day's first haul; a missing anchor-bar bolt would put the sling load on one bolt.

**Recommended next step.** Amish to answer register item 1; then, when the phase allows, TRL 4 as already recommended, with the R1 trial run using both boxes.

## Session 2026-10-03: TRL 3 (kit 1.7.0, /to-trl3 under Amish's pre-approval)

Amish, 2026-10-03: "start with the first 14 repos from the list of 29 projects. I pre-approve the batch runs along with any recommendations you come up with. I also accept any cost overruns or variations from the assumed scope cost." Every recommendation in this session is therefore recorded as decided, dated 2026-10-03, in `docs/06-design-decisions.md`. Kit 1.7.0 was installed from the kit source; `.kit/PHASE.yaml` kept as installed.

### TRL 2

**What was done.**

- `docs/01-problem.md` (SLH-PRB-001 v0.2): first co-design candidate, safety note, questions for the first trials.
- `docs/03-requirements.md` (SLH-REQ-001 v0.2): measurable targets; R11 (overload limit) and R12 (holds when let go) added.
- `docs/02-concept.md` (SLH-PRC-001 v0.2): how it works, components, first-order numbers, key design choices, safety.
- `docs/decisions/0001-trl2-review-decisions.md` (SLH-DDR-001): thirteen TRL 2 review items decided.

**Results.** First-order working pull about 1 kN; crank force well inside 150 N with a 4:1 drive; output limited by hand power to well below a bucket crew.

**Requirements not met.** R1 (output) was already short at TRL 2 and is kept as the trial target.

**Decisions made under the pre-approval.** SLH-DDR-001, items 1 to 13: split winding drum; 4:1 chain drive; shear pin (R11); two ratchet wheels on the drum shaft (R12); tail block on floor anchors only; sling anchor with stakes only against skating; 10 mm rope; box open toward the door with forward tipping; two people to tip; capstan 6 m or more from the door; Kerala State Disaster Management Authority as first co-design candidate (not agreed); capstan as candidate common block for SaltDrag and CalRig as first proof-load rig; budget kept.

**Safety concerns.** Rope whip from a failed anchor or rope; entrapment at the chain, drum and cranks; uncontrolled stall loads without an overload limit; weak walls as anchors.

### TRL 3

**What was done.**

- `docs/04-calcs/01-sizing.md` and `docs/04-calcs/sizing.py` (SLH-CAL-001 v0.2), `docs/04-calcs/results.csv`.
- `cad/src/model.py`: parametric build123d model with constructability checks (no overlaps, no floating parts); STEP and STL in `cad/step` and `cad/stl` (capstan, box, tail, ramp; assembly STEP at the design case).
- `cad/src/sheets.py`: SLH-DWG-001 (hand capstan GA) and SLH-DWG-002 (system layout), Rev P2.
- `bom/bom.csv`: 23 lines, all priced, with suppliers by type.
- `cad/src/concept_media.py`: `media/hero.png`, `exploded.png`, `flow.png`, `concept-blueprint.png` and `.pdf` (SLH-DWG-010), `model.glb` (1.6 MB, coarse tessellation) and `viewer.html`. No cutaway (the inside does not matter).
- `docs/decisions/0002-design-for-construction.md` (SLH-DDR-002); `design_state: constructable`.
- `cad/src/build_plan_media.py`: overview, nine making sketches (SLH-DWG-101 to 109), eight joint close-ups and twelve step pictures; `docs/05-build-plan.md` (SLH-BLD-001) and `docs/06-design-decisions.md` (SLH-DEC-001).
- `cad/src/product_model.py` (`product_parts()`, `TITLE`, `RENDER_VIEWS` hero, exploded, detail); scenes exported to `/home/claude/renders/silthaul` (three .npz and .json, `silthaul__jobs.json`). Photoreal renders, captions and cards are made on Amish's Mac; the README already leads with `media/render-hero.png`.
- `README.md`, `project.yaml` (trl 3, trl_target 3).

**Results (SLH-CAL-001).** Working pull 1,000 N (917 N estimated); 63 N per person with two at the cranks; 5.4 m/min loaded; 5.65 min a trip over 11 m; 0.43 m³/h (0.32 with rest); shear pin releases at about 2,450 N, all parts sized on 3,000 N; rope factor 18 working and 5.4 at the limit; chain factor 5.0; tail anchors at 0.45 of recommended loads at the limit; heaviest lift 24.7 kg (frame) and 23.1 kg (drum with bearings); kit about 132 kg. Value-engineering target: USD 2,000. Estimated cost of the constructable design: USD 887.50 (USD 1,112.50 under the target).

**Requirements not met.**

- **R1, not met on paper:** 0.32 against about 0.90 m³/h for a bucket crew (ratio 0.36, target 2). Two people at a crank give about 50 W each; dragging 1 kN uses it all.
- **R9, at risk:** mass is met (24.7 kg) but the 890 x 663 x 814 mm frame needs an estate car or small pickup.
- **R8, not verifiable at TRL 3:** about 17 min estimated.

**Decisions made under the pre-approval.** SLH-DDR-002, the thirteen design-for-construction changes (listed below); keeping R1 as the trial target; the appearance model additions (below). All in `docs/06-design-decisions.md`; open decisions: none.

**Build plan findings (design changes made for construction, SLH-DDR-002).**

1. Frame in 40 x 40 x 2 tube with 8 mm plates: 24.7 kg (was over 25 kg).
2. Anchor bar and eye 200 mm up, level with the drum axis; at ground level the capstan could tip at the overload limit.
3. Bearing pads narrowed to 50 mm to clear the first ratchet wheel.
4. Lighter drum (4 mm rings and discs with lightening holes, 6 mm ratchet wheels): 23.1 kg with bearings.
5. Ratchet wheel 1 and its pawl mirrored to the front so each pawl clears the teeth behind its nose.
6. Sprocket hub 36 mm; guard and cranks moved outboard to clear the chain.
7. Shear pin detailed through a free-running hub.
8. Stake heads that rest on the stake tubes.
9. Tail block of two 125 mm sheaves on 25 mm pins with spacers, keeper and four anchors.
10. Box 450 mm wide so the return rope passes beside it in a 0.7 m door.
11. Sloped back and cut skids so the box rides over mud on the return.
12. Bridle lugs, shackle pins and chain legs defined.
13. Ramp decks as folded trays bolted through the cheeks; roller 10 mm proud.

**Appearance model.** `product_model.py` uses the `model.py` solids in the shortened picture layout. Additions not in `model.py`: rope wound on both drum halves, stakes shown above ground only, a wall with a doorway, a tree as the anchor and a 1.75 m mannequin (`mannequin()`, standing at the +Y crank facing the capstan). Decided under the pre-approval.

**Safety concerns.**

- Rope whip: the shear pin bounds rope tension, but a pin replaced by a bolt removes the bound; the briefing card and stop 6 say so.
- The tail block depends on a sound slab; stop 2 forbids use without one. A door-frame option needs pull tests first.
- Tipping the full box takes about 203 N; two people, and only with a pawl holding.
- Sling geometry: a sling rising more than 10 degrees can tip the capstan at the overload limit.
- Entrapment at the drum where the rope winds on is not guarded (the drum must stay open for the rope); people stay out of the rope area while cranking.
- Clean-up hazards (structure, electricity, contamination) remain with users.

**Recommended next step.** The design is ready for TRL 4 when the phase allows: build the capstan and tail block, run the R11 shear pin release test and the proof loads on CalRig, then the timed R1 trial against a bucket crew with the first co-design candidate. Suggestions not added to the repo: a second box on the return leg so both strokes carry mud (would roughly double output; changes the product); a bolted, flat-packing frame for R9.

## Session 2026-09-30: scaffolded

### What was done

- Repository created from kit 1.6.0 at TRL 1, target TRL 2.
- `docs/01-problem.md` (SLH-PRB-001 v0.1): problem with cited evidence, users, environment, constraints, prior work, open questions.
- `docs/02-concept.md` (SLH-PRC-001 v0.1): how it works, components, patent design-arounds, shared blocks, safety.
- `docs/03-requirements.md` (SLH-REQ-001 v0.1): 10 proposed requirements.
- `README.md` with concept rationale, burning platform, where it could be used, and what sparked the idea.

## 2026-10-03: photoreal renders

Rendered with Blender Cycles on Amish's Mac from `cad/src/product_model.py`; captioned with `.kit/photo_caption.py`; `media/card.png` and `media/social-preview.png` made with `.kit/cards.py`. Views: hero, exploded, detail. image_qc passes and `render.py --check` has no FAIL.

## 2026-10-03: photoreal renders redone after Amish's requirement decisions

Rendered with Blender Cycles on Amish's Mac from `cad/src/product_model.py`; captioned with `.kit/photo_caption.py`; `media/card.png` and `media/social-preview.png` made with `.kit/cards.py`. Views: hero, exploded, detail. image_qc passes and `render.py --check` has no FAIL.

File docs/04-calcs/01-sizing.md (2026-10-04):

---
doc_id: SLH-CAL-001
title: SiltHaul sizing calculations
project: SiltHaul
doc_type: Calculation
version: "0.4"
status: Draft
date: '2026-10-03'
author: Amish Chadha
license: CERN-OHL-S-2.0
revisions:
- version: "0.1"
  date: '2026-10-03'
  author: Amish Chadha
  change: First issue for TRL 3 (haul force, crank force, speed and output, drum storage, overload limit, rope, anchors, shafts and chain, stability, doorway fit, setup, mass, cost)
- version: "0.2"
  date: '2026-10-03'
  author: Amish Chadha
  change: Rerun on the constructable design (SLH-DDR-002); anchor bar at drum axis height, 25 mm sheave pins, lighter drum
- version: "0.3"
  date: '2026-10-03'
  author: Amish Chadha
  change: Rerun for Amish's requirement decisions (SLH-DDR-003); second box on the return leg (two-box stroke, output against the restated R1); flat-pack frame and pack check (R9); tail block, setup, mass and cost updated
- version: "0.4"
  date: '2026-10-03'
  author: Amish Chadha
  change: "R9 restated per Amish's round-2 decision 2A (SLH-DDR-004); no numbers changed"
---

# SiltHaul sizing calculations

On paper SiltHaul now meets its output requirement as Amish restated it on 2026-10-03 (SLH-DDR-003, decision 2A): "no lifting or carrying of mud; output at least 0.5 times the same crew with shovels and buckets". A second box rides on the return leg of the rope loop, so every stroke hauls one full box out while the other goes back empty to be filled. A crew of four moves about 0.68 m³ an hour, 0.51 m³ an hour with a rest allowance, against about 0.90 m³ an hour for a bucket crew of the same four people: a ratio of 0.57 against the 0.5 asked. One box alone gave 0.43 m³ an hour. The two boxes are 210 mm wide inside so that they pass each other 42 mm apart in the room and both cross the doorway ramp in a 0.7 m door; each holds 40.3 L. Two people at the cranks need 63 N each at the 1,000 N working pull, the rope and every anchor keep a factor of at least 5 on the rope tension that the shear pin allows, and the frame now packs flat (decision 7A): two side frames of 9.2 and 9.6 kg and four bolted cross members, with the drum and its bearings the heaviest lift at 23.1 kg. The kit packs into about 454 L, 77 % of a small hatchback's boot with the rear seats folded. Value-engineering target: USD 2,000. Estimated cost of the constructable design: USD 1,055.60 (USD 944.40 under the target). Eleven of the twelve requirements are met on paper or by design, and one, R8 (setup time, now at its 20 min limit), can only be verified by a timed trial. Every number in this note is printed by `docs/04-calcs/sizing.py`; the tag in brackets, for example [B3], is the line of that script's output that carries it.

> **Safety:** SiltHaul is a rope-and-anchor system under tension with a hand-cranked chain drive. A failed anchor, rope or shackle can whip, and the chain, sprockets and cranks can trap fingers. These are first-principles estimates for a paper proof of concept; they do not show that any part is safe. Every anchor, the rope and the capstan must be proof-loaded before use (SLH-BLD-001, section 6), and nobody stands in the line of a rope or beside a sheave while the cranks turn. See SLH-PRC-001, Safety.

## Scope and method

The note checks every requirement in SLH-REQ-001 v0.4 against the design in SLH-PRC-001 v0.3 and the parametric model `cad/src/model.py`. The script imports the model's `PARAMS`, `derived()` and `masses()`, so the drum, frame, box and tail block used here are the ones in the STEP files and drawings SLH-DWG-001 and 002. It also reads `bom/bom.csv` and `budget_usd` in `project.yaml`, and writes `docs/04-calcs/results.csv`.

The design case is a ground-floor room 7 m long, with the tail sheave block at the far wall, the doorway threshold 7 m from it and the capstan drum 15 m from it (R5). Box 1, on the pull rope, is hauled 11 m from the far end of the room to a dump point outside, while box 2, on the return rope, comes back 11 m from its dump point to the far end of the room; the next stroke reverses them. A 12.5 m tail rope joins the two boxes round the tail sheaves.

## Assumptions

*Table 1. Main assumptions.*

| Area | Assumption | Basis |
| --- | --- | --- |
| Mud | Density 1.70 kg/L (range 1.5 to 1.8); undrained shear strength 3 kPa (soft mud is 1 to 5 kPa) | Handbook ranges for soft silt and clay |
| Friction | Steel skids on a mud-covered floor 0.70; on the wet steel ramp 0.40 | Conservative screening values |
| Lip | Cuts a 40 mm layer of mud with a bearing factor of 6 | Assumed |
| Rope | 10 mm polyester double braid, MBS 18 kN, 0.065 kg/m; eye splices keep 90 % | Typical catalogue figures |
| Drive | Chain 95 %, each bearing 98 %; cranks 250 mm | Typical figures |
| People | 30 rpm at the cranks with a full box, 45 rpm empty; a short heave of 400 N on a crank | Ergonomic ranges for sustained cranking |
| Trip | Loading 1.5 min, dumping 0.75 min plus 0.25 min for the crank crew to walk to the box and back; haul 11 m | Estimates |
| Boot | Small hatchback with the rear seats folded: 1,250 x 950 x 500 mm (594 L); boxed pieces may take 80 % of it | Assumed typical size; confirmed by a pack test |
| Buckets | Two shovellers each fill 10 L a minute of wet mud; carriers keep up | Estimate; no published rate found for flood mud |
| Rest | People work 75 % of the time in heat and wet | Estimate |
| Shear pin | S235 bar, ultimate shear strength 240 MPa, scatter ±20 % | 0.6 times 400 MPa tensile |
| Anchors | M12 wedge anchor in sound concrete: 4 kN tension and 6 kN shear recommended loads | Typical published values; to be confirmed on the product bought |

## A. Box capacity and load (R3)

There are now two identical boxes. Each is 210 mm wide inside and 845 mm long to the lip, with 280 mm sides and a back that slopes 110 mm. Filled level to 245 mm it holds 40.3 L, and 46.1 L to the brim [A1]. A box and its bridles weigh 17.2 kg; 40.3 L of mud weighs 68.5 kg, so a full box is 85.7 kg, or 841 N [A2]. The narrow, long box keeps the 40 L of R3 while leaving room for both boxes on lines 300 mm apart (section L).

## B. Haul force

Dragging a full box across the floor takes 589 N of friction plus 154 N for the narrower lip cutting through mud, 743 N in all [B1]. Over the 18.9 degree doorway ramp it takes 590 N, and the ropes add about 10 N of drag [B2]. The haul pull estimate for one box is 752 N; the design keeps a working pull of 1,000 N [B3]. Pulling an empty box back takes about 228 N with the rope drag [B4]. With two boxes on the loop each stroke does both at once: 752 N for the full box going out and 218 N for the empty one coming back, 970 N, still inside the 1,000 N working pull [B5].

## C. Crank force (R2)

The rope sits on the drum at a 114.5 mm radius; the chain gives 4:1 and the drive is about 91 % efficient [C1]. At the 1,000 N working pull each of two people pushes 63 N on a handle, or one person 126 N, both inside the 150 N of R2 [C2]. At the 970 N stroke estimate it is 61 N each, or 122 N for one person [C3].

## D. Speed, cycle and output (R1)

At 30 rpm on the cranks the rope moves 5.40 m a minute with a full box going out and the empty one coming back [D1]. A stroke works like this: at the end of each haul one box stands at the far end of the room and the other at the dump. The two loaders fill the box in the room (1.5 min) while the two people from the cranks walk to the other box, tip it with the tipping bar and walk back (0.75 min plus 0.25 min). Then the cranks turn the other way and haul for 2.04 min. A stroke takes 3.54 min and delivers one full box [D2]. That is 17.0 strokes and 0.68 m³ an hour with a crew of four, each person at the cranks putting in about 48 W; with one box the same crew managed 0.43 m³ an hour [D3].

*Table 2. Output against a bucket crew [D4, D5].*

| Crew of four | Output with rest | People lifting or carrying mud |
| --- | --- | --- |
| Shovels and buckets (two filling, two carrying) | 0.90 m³/h | All four; each cubic metre is 1.7 t lifted about 1 m and about 2.2 km walked carrying 10 L buckets |
| SiltHaul, two boxes (two cranking and dumping, two loading) | 0.51 m³/h | None; loaders push mud in over the lip at floor level |

The ratio is 0.57 against the 0.5 of R1 as Amish restated it, so **R1 is met on paper**, and nobody lifts or carries mud. The margin is small and rests on estimated loading, dumping and bucket rates; the timed trial of R1 at TRL 4 settles both numbers. Hand power still sets the haul speed: the second box doubles what each stroke delivers, not how fast the rope moves.

## E. Drum and rope storage (R5)

The drum has a 229.1 mm pitch diameter, 720 mm of rope a turn. Twelve metres of box travel is 16.7 turns, and each half stores 21 turns, which includes three dead turns and one spare [E1]. Each half is 236 mm long at an 11 mm winding pitch, and the drum is 484 mm between its outer faces [E2]. The drum is smooth, so the rope must reach it at no more than about 1.5 degrees from square. With the capstan 6 m from the ramp roller the worst fleet angle is 1.41 degrees, and 1.06 degrees at the design case of 8 m [E3, E4]. The capstan therefore stands at least 6 m beyond the door, which leaves rooms up to 9 m long within the 15 m of R5.

## F. Overload limit (R11)

A 4 mm S235 pin in double shear across the 25 mm crank shaft carries 75.4 N m, which is a rope tension of 2,451 N when it shears [F1]. With ±20 % scatter it releases between 1,961 and 2,941 N, so the design maximum rope tension is 3,000 N [F2]. Without the pin, two people heaving 400 N each on the cranks could put 6,372 N into a jammed rope [F3]; the pin is what lets every part below be sized on 3,000 N.

## G. Rope (R6)

An 18 kN rope, 16.2 kN through an eye splice, has a factor of 18 on the working pull and 5.4 on the overload limit [G1]. The rope bends round the drum at 22 times its diameter, round the tail sheaves at 12.5 and over the ramp roller at 6, where it turns only a few degrees [G2].

## H. Capstan anchor and stability

The capstan anchor carries 1,100 N while hauling and 3,250 N at the overload limit; the 2,000 kg round sling has 19.6 kN of working load, six times that, and each shackle 9.8 kN [H1]. The capstan, with its bolted frame, weighs 65.7 kg and its weight holds 271 N m about its front edge [H2]. The sling is shackled to an eye 200 mm up, level with the drum axis, so the rope pull and the sling pull nearly line up. With the sling level the frame is held back by 315 N m; with it rising 5.7 degrees by 54 N m; at 10 degrees the tipping moment is 145 N m, still inside the 271 N m [H3 to H5]. The anchor bar that carries the sling is now bolted between the rear braces with two M12 bolts at each end, each in shear at about 1.6 kN at the overload limit. The rule is therefore that the sling runs level or rises 10 degrees at most, for example a 3 m sling to a point no higher than 500 mm. The ground stakes stop the frame skating sideways and are not counted as the anchor.

## I. Tail sheave block (R7)

With two boxes the tail rope always drags the empty box back, so the tail block carries about 636 N on either stroke. If a box going back jammed and the crew cranked until the pin sheared, it would carry both legs at 3,000 N, 6,000 N in all [I1]. Each of the four M12 anchors then takes 1,500 N of shear and 818 N of tension, 0.45 of the typical recommended loads [I2]. Each 25 mm sheave pin takes 4,243 N at 50 mm above the plate, a bending stress of 138 MPa against 355 MPa yield [I3]. R7 is met on paper on a sound concrete slab; the anchors are only as good as the slab, which is checked on site (SLH-BLD-001, section 6).

## J. Shafts, chain and ratchet (R12)

At the overload limit the 30 mm drum shaft sees 44 MPa of bending and 65 MPa of torsion, 121 MPa combined [J1]. The chain pull is 3,539 N, a factor of 5.0 on the 17.8 kN breaking load of ISO 08B-1 chain [J2]. The 25 mm crank shaft sees 93 MPa combined before the cross hole; the hole roughly doubles the local stress, which stays below yield [J3]. A ratchet tooth carries 4,091 N, 57 MPa on its 12 x 6 mm face, and the pawl pin 36 MPa in shear [J4].

## K. Stability in the haul and tipping at the dump

A full box has its centre of mass 458 mm behind the lip, so its weight holds it level with 385 N m [K1]. The pull at the bridle ring, 75 mm up, tries to tip it nose-down with 75 N m at the working pull and 225 N m at the overload limit, both less [K2]. To dump, the end of the tipping bar is lifted 1,539 mm behind the lip: about 236 N to start a full box, falling as the mud slides out [K3]. That is more than one person should lift repeatedly, so the two people from the cranks share the bar, about 118 N each.

## L. Doorway fit, setup, mass, packing and cost (R4, R8, R9, R10)

Each box is 214 mm wide and 258 mm over its shackle pins. On lines 300 mm apart the two boxes pass each other 42 mm apart in the room, and the ramp, now centred between the two lines, carries both 26 mm inside its cheeks; it is 646 mm outside, inside a 700 mm opening [L1]. The model checks both clearances. Setting up takes about 27 min of tasks, about 20 min with three people working in parallel, at the R8 limit, because the frame is bolted together on site (3 min) and two boxes are shackled (4 min); only a timed trial can confirm it [L2]. The heaviest single lifts are the drum with its bearings at 23.1 kg, a box at 16.1 kg, the tail plate at 11.0 kg and a side frame at 9.6 kg [L3].

The flat-pack frame comes apart into two welded side frames, each 890 x 814 x 83 mm and 9.2 or 9.6 kg, and four cross members 516 mm long: the front and rear cross rails, the top tie and the anchor bar with its eye [L3a]. Each cross member has an 8 mm end plate at each end that bolts to the inside face of a side frame, with two M10 bolts for the rails and the tie and two M12 bolts for the anchor bar. Taking a small car boot as a small hatchback with the rear seats folded, 1,250 x 950 x 500 mm or 594 L, every piece fits and the boxed volume of the kit is about 454 L, 77 % of the space, with the rope bag, crank bearings and chain (30 L) carried inside the boxes and the ramp taken apart [L3b]. R9 is therefore met on paper with the seats folded. With the seats up the load floor is about 950 x 650 mm and the side frames do not lie flat in it [L3c]; whether that reading of "small car boot" is enough is put to Amish in the design decisions register.

Value-engineering target: USD 2,000. Estimated cost of the constructable design: USD 1,055.60 (USD 944.40 under the target) [L4]. The rise of USD 168.10 is the second box (USD 80), its bridles (USD 54), 7 m more rope, the frame's end plates and drilling (USD 10), twelve frame bolts (USD 8) and paint (USD 5). The whole kit weighs about 154 kg with rope and sling [L5].

## M. Results against every requirement

*Table 3. Requirement status from this note [M].*

| ID | Requirement | Value | Target | Status |
| --- | --- | --- | --- | --- |
| R8 | Setup time | About 20 min with three people (estimate), at the limit | 20 min or less | Not verifiable at TRL 3 |
| R1 | Output | 0.51 m³/h against 0.90 m³/h for buckets (ratio 0.57); nobody lifts or carries mud | No lifting or carrying of mud; at least 0.5 times the bucket crew | Met on paper |
| R9 | Portability | Heaviest lift 23.1 kg; flat-pack frame, largest piece 890 x 814 x 83 mm; kit about 454 L in a 594 L small car boot | Restated R9: fits a small hatchback with the rear seats folded; heaviest part 25 kg or less | Met on paper (accepted by Amish, SLH-DDR-004) |
| R2 | Crank force | 63 N each with two at the cranks (126 N for one) at 1,000 N | 150 N or less | Met on paper |
| R6 | Rope and anchor strength | Rope factor 18 working, 5.4 at the 3,000 N limit; chain 5.0 | At least 5 times the working pull | Met on paper |
| R7 | Tail anchor independent of walls | Four M12 anchors in the slab, 0.45 of recommended loads at the limit | Holds on a bare concrete floor, no wall contact | Met on paper (sound slab assumed) |
| R10 | Cost | USD 1,055.60 | Value-engineering target USD 2,000 | Met on paper, within the target |
| R11 | Overload limit | Shear pin releases at 2,451 N (1,961 to 2,941 N) | Rope tension limited to 3,000 N | Met on paper |
| R3 | Box capacity | 40.3 L a box at a 245 mm fill (46 L to the brim) | About 40 L | Met by design |
| R4 | Fits a doorway | Boxes 258 mm over the shackles, pass 42 mm apart; ramp 646 mm; tail plate 440 mm | Pass a 0.7 m opening | Met by design |
| R5 | Working length | 21 turns a half store 12 m of travel; capstan at least 6 m from the door | Up to 15 m tail to capstan | Met by design |
| R12 | Holds when let go | Two ratchet wheels and pawls on the drum shaft, one each way | Holds the load when the cranks are let go | Met by design |

Counts: 1 not verifiable at TRL 3, 7 met on paper, 4 met by design; none not met or at risk.

## Checks against the TRL 2 figures

| TRL 2 claim (SLH-PRC-001 v0.2) | This note | Action |
| --- | --- | --- |
| Friction capstan with a rope loop | A loop on a friction drum needs a pretension of about half the pull and walks along the drum | Split winding drum (SLH-DDR-002) |
| Working pull about 1 kN | 917 N estimate; 1,000 N used | None |
| Twice the bucket output | 0.36 times with one box; 0.57 with two | R1 restated by Amish to 0.5 times and met with a second box (SLH-DDR-003) |
| Anchors sized on the working pull | A jammed box and two heaving people reach 6.4 kN | Shear pin limits rope tension to 3,000 N (R11) |

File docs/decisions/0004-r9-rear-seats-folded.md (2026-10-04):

---
doc_id: SLH-DDR-004
title: SiltHaul R9 accepted with the rear seats folded
project: SiltHaul
doc_type: Design decision record
version: "0.1"
status: Draft
date: '2026-10-03'
author: Amish Chadha
license: CERN-OHL-S-2.0
revisions:
- version: "0.1"
  date: '2026-10-03'
  author: Amish Chadha
  change: Amish's round-2 decision 2A on R9 recorded
---

# 0004: R9 accepted with the rear seats folded

- **Date:** 2026-10-03
- **Status:** decided by Amish, 2026-10-03 (round 2): "i agree with all the 46 recommendations you provided. please proceed." For SiltHaul this is decision 2A, the open decision in SLH-DEC-001 v0.2.

## Context

With the bolted flat-pack frame (SLH-DDR-003) the kit packs into about 454 L, 77 % of a small hatchback's load space with the rear seats folded (1,250 x 950 x 500 mm, 594 L). With the seats up, the 890 x 814 mm side frames do not lie flat in a typical 950 x 650 mm boot floor.

## Options considered

| Option | What it means |
| --- | --- |
| A (chosen) | Accept the rear seats folded as the reference; record R9 as met on paper |
| B | Split each side frame into bolted tubes so everything fits with the seats up: about forty bolts and well over 20 min of setup, which breaks R8 |

## Decision

Option A. R9 is restated as "fits a small hatchback with the rear seats folded; heaviest part 25 kg or less". No design change: the frame, the parts and the mass are as in SLH-DDR-003.

*Table 1. Effects.*

| Item | Result |
| --- | --- |
| R9 | Met on paper: heaviest lift 23.1 kg; kit about 454 L packed against 594 L |
| Other requirements | None changed; R8 stays about 20 min, at its limit |
| Cost | Unchanged. Value-engineering target: USD 2,000. Estimated cost of the constructable design: USD 1,055.60 (USD 944.40 under the target) |
| Documents | Requirements v0.5, calculation note v0.4 (wording only), build plan v0.3 (pack check wording), register v0.3 |

## Safety

> **Safety:** SiltHaul is a rope-and-anchor system under tension with a hand-cranked chain drive; proof-load tests come before use. Packing the heavy parts into a car is a manual-handling task: no lift is heavier than 25 kg, and two people share the drum with bearings (23.1 kg). Flood mud may carry sewage and disease; use boots, gloves and hygiene measures.

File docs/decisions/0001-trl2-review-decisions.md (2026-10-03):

---
doc_id: SLH-DDR-001
title: SiltHaul TRL 2 review decisions
project: SiltHaul
doc_type: Design decision record
version: "0.1"
status: Draft
date: '2026-10-03'
author: Amish Chadha
license: CERN-OHL-S-2.0
revisions:
- version: "0.1"
  date: '2026-10-03'
  author: Amish Chadha
  change: TRL 2 review items decided under Amish's pre-approval of 2026-10-03
---

# 0001: TRL 2 review decisions

- **Date:** 2026-10-03
- **Status:** accepted

## Context

The TRL 2 review (`docs/REVIEW.md`, TRL 2 section) raised the items below. On 2026-10-03 Amish wrote: "start with the first 14 repos from the list of 29 projects. I pre-approve the batch runs along with any recommendations you come up with. I also accept any cost overruns or variations from the assumed scope cost." Every recommendation is therefore decided as recommended. Choices that touch safety take the conservative option, with the evidence that would relax them stated. Partners and regions are the first candidates to approach, not agreements.

## Options considered

Table 1 lists the options for each item and the one chosen.

## Decision

*Table 1. Items decided on 2026-10-03 under Amish's pre-approval.*

| # | Item | Options | Decision | What would relax a safety choice |
| --- | --- | --- | --- | --- |
| 1 | Capstan type | (a) friction capstan with the rope loop wrapped round it; (b) split winding drum, one half winding while the other pays out | (b). A friction loop needs a pretension of about half the pull and its turns walk along the drum; a winding drum cannot slip | Not a safety choice |
| 2 | Drive | (a) direct crank; (b) 4:1 roller chain to a crank shaft at standing height, two cranks | (b): 63 N per person at 1 kN | Not a safety choice |
| 3 | Overload | (a) size everything on what two people can heave (6.4 kN); (b) a shear pin that limits rope tension to about 2.5 kN | (b), conservative: R11 added. Every part is sized on 3,000 N | Release tests on a batch of pins showing a tighter scatter could raise the working pull, never the limit |
| 4 | Holding | (a) one pawl on the crank shaft; (b) two opposite ratchet wheels and pawls on the drum shaft | (b), conservative: R12 added. The drum holds either way even if the chain or pin fails | None proposed |
| 5 | Tail anchor | (a) floor plate on drilled anchors; (b) door-frame spanning bar; (c) strut | (a) only, conservative. Walls and door frames are never used | Pull tests to 5 times the R11 limit on representative flood-damaged frames would allow (b) as an option |
| 6 | Capstan anchor | (a) ground stakes; (b) round sling to a tree or parked vehicle, stakes against skating | (b), conservative; the sling runs level or rises 10 degrees at most | Pull tests of stakes in wet soil to 5 times the anchor load would allow stakes alone |
| 7 | Rope | 8 mm or 10 mm polyester double braid | 10 mm, 18 kN: factor 5.4 on the limit through a splice | Not relaxed |
| 8 | Box | (a) open front facing the room, filled by hand; (b) open front facing the door, scooping on the way out and tipping forward at the dump | (b), with a sloped back that rides over mud on the return | Not a safety choice |
| 9 | Dumping | One person or two on the tipping bar | Two people, conservative: about 203 N to start a full box | A lift under 150 N measured at TRL 4 would allow one person |
| 10 | Capstan distance from the door | 4 m, 6 m or more | At least 6 m, for a fleet angle of 1.41 degrees or less on the smooth drum | Not a safety choice |
| 11 | Co-design partner | NGO, municipal unit or volunteer fire service | First candidate to approach: the Kerala State Disaster Management Authority and its civil defence volunteers (not agreed) | |
| 12 | Shared blocks | Hand capstan common block with SaltDrag; CalRig for proof loads | SiltHaul's capstan is recorded as the candidate common block; SaltDrag is checked against it at its own TRL 3 (not edited here). CalRig is the first candidate rig for proof loads | |
| 13 | Budget | Keep `budget_usd` at 2,000 | Kept; it is a value-engineering target, not a limit | |

## Consequences

- R11 (overload limit) and R12 (holds when let go) are added to SLH-REQ-001.
- The design for construction (SLH-DDR-002) works from these choices.
- R1 is reported not met on paper; Amish's pre-approval covers the recommendation to keep R1 as the trial target rather than lower it, so the TRL 4 timed trial settles it.

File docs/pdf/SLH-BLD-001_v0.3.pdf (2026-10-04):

S I LT H A U L · B U I L D P L A N

# SiltHaul prototype build plan

Design Molecule Lab · designmolecule.com

D O C U M E N T CO N T RO L

Document ID | SLH-BLD-001 | Version | 0.3
Status | Draft | Date | 2026-10-03
Author | Amish Chadha | License | CERN-OHL-S-2.0
Project TRL | TRL 3 | Proof of concept
Repository | github.com/BoujeeEnjinia1701/silthaul
Source | docs/05-build-plan.md @ uncommitted

R EV I S I O N H I STO RY

Version | Date | Author | Change
0.3 | 2026-10-03 | Amish Chadha | Pack check worded to R9 as restated by Amish (SLH-DDR-004); no design change
0.2 | 2026-10-03 | Amish Chadha | Second scraper box on the return rope and a bolted flat-pack frame (SLH- DDR-003, Amish's decisions 2A and 7A); steps renumbered
0.1 | 2026-10-03 | Amish Chadha | First build plan; design made constructable (SLH-DDR-002)

D R A F T · N O T F O R F A B R I C A T I O N

## SiltHaul prototype build plan

Plan, not yet built. How to build the first proof-of-concept prototype, component by component. Building and testing to it is TRL 4 work. Decisions are kept in the design decisions register (docs/06-design-decisions.md), not here.

### 1. What you are building

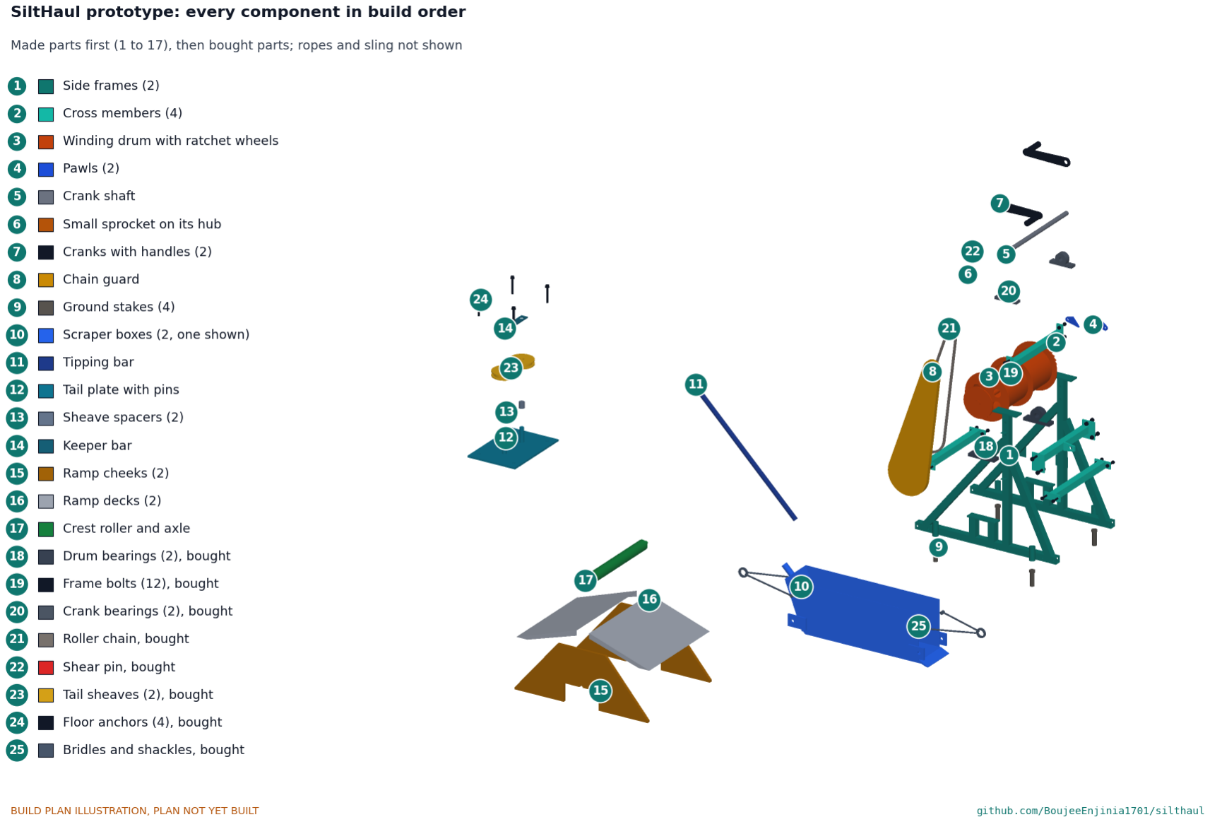
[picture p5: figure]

Figure 1. Every component pulled apart and numbered in build order: made parts 1 to 17, bought parts 18 to 25. Only one of the two scraper boxes is shown.
The prototype is a hand-cranked rope haul for flood mud: a capstan that stands outside, a tail sheave block bolted to the floor at the far end of the room, a ramp across the doorway threshold, two steel scraper boxes and three ropes that join them in a loop. One box rides on the pull rope and the other on the return rope, so every turn of the cranks hauls one full box out while the other goes back empty. The capstan frame packs flat: two welded side frames joined on site by four bolted cross members. You weld the side frames, the cross members, the drum, the boxes and the tail plate from stock steel tube, plate, sheet and bar; profile-cut the ratchet wheels and pawls; make the ramp from plywood and folded sheet; and buy the bearings, sprockets, chain, sheaves, anchors, shackles, bolts, sling and rope. The parts cost about USD 1,056 from the bill of materials. The work needs a MIG welder or a small stick welder, a pillar drill and hand tools.

Safety: SiltHaul works with ropes and anchors under tension and a chain drive turned by hand. A failed anchor, shackle or rope can whip; the chain, sprockets, drum and cranks can trap fingers and clothing. The building work involves welding, grinding and drilling concrete. Nobody turns the cranks with the chain guard off, and nothing is loaded before the safety stops in section 6 allow it. Load tests are TRL 4 work.

### 2. What changed to make it buildable

The concept showed what SiltHaul does; some of its parts could not be made or fitted as drawn. Each change keeps what SiltHaul does and is recorded in decision record SLH-DDR-002. The last two rows came later, from Amish's decisions on the requirements, and are recorded in SLH-DDR-003.
Table 1. Changes from the concept.
Component | The concept had | The buildable design has | Why
Capstan | A friction capstan with the rope loop wrapped round it | A drum in two halves: one winds the pull rope while the other pays out the return rope (Figure 5) | Cannot slip, needs no pretension, the turns cannot walk along the drum
Drive | Crank on the drum | 4:1 chain from a crank shaft 850 mm up, two cranks (Figure 13) | 63 N per person at the working pull
Overload | None | A 4 mm shear pin in the small sprocket's hub (Figure 9) | Rope tension never passes about 2.5 kN
Holding | One ratchet | Two opposite ratchet wheels on the drum shaft, one pawl in front and one behind (Figure 10) | Holds either way, even if the chain fails
Frame | 40 x 40 x 3 tube, sling at ground level | 40 x 40 x 2 tube; anchor bar and eye 200 mm up (Figure 11) | Under 25 kg; the sling pulls in line with the ropes
Box | Width not set; open front toward the room | 450 mm wide, open front toward the door, sloped back, lugs for bridles (Figure 15) | Box and return rope pass a 0.7 m door together; scoops going out, rides over mud coming back
Tail block | One sheave on a floor plate, or a door-frame bar | Two 125 mm sheaves on 25 mm pins, keeper bar, four floor anchors (Figure 17) | Bought sheaves; never bears on a wall
Doorway guard | Rope guard on the frame | Ramp with plywood cheeks and a crest roller (Figure 19) | Carries the boxes and the ropes over the threshold
Boxes | One 450 mm box; the return rope came back empty | Two boxes 210 mm wide inside and 845 mm long, one on each rope, joined by a tail rope round the tail sheaves (Figure 15) | Mud goes out on every stroke; the boxes pass each other and both fit the ramp in a 0.7 m door
Frame | One welded frame, 890 x 663 x 814 mm | Two welded side frames and four bolted cross members (Figures 2, 3 and 4) | Packs flat into a small car boot

### 3. Making the components

Make and check each component before the step that needs it. Sizes are in millimetres. "Front" is the side of the capstan that faces the house; "+Y side" is the side with the ratchet wheels, "-Y side" the side with the chain. Workshop tolerance is 1 mm unless a step says otherwise. Weld the 2 mm tube with MIG or 2.5 mm electrodes; fillets are 3 mm on tube and 5 mm on plate unless stated. Mark every part with its name in paint marker.

### 3.1 Capstan side frames

Figure 2. Capstan side frames making sketch (SLH-DWG-101).
What it is and what it is made from. The two welded sides of the capstan frame, which carry the drum bearings, the crank bearings and the pawls. They are joined on site by the cross members (section 3.2). 40 x 40 x 2 mm steel square tube; 8 and 6 mm plate; 12 mm bar; 33.7 x 3.2 mm tube.
How to make it.
For each side frame cut a rail 890 long, a post 765 long and two pad posts 99 long. Cut the braces to fit in step 4. Lay the rail flat. Weld the post upright 150 mm behind the drum axis line and the two pad posts 60 mm each side of the axis line; check square.
Weld a bearing pad (180 x 50 x 8) on the two pad posts, its top 157 mm above the floor. Weld a top plate (150 x 60 x 8) on the post, its top 813 mm up.
Fit the front brace from 60 mm in from the front end of the rail to the post near 640 mm up, and the rear brace from 50 mm in from the rear end to the post near 560 mm up. Cut the ends to fit and weld.

1.
2.

3.

4.

Weld a stake tube (33.7 x 3.2 x 80) upright on the outside of the rail, 280 mm in front of and 330 mm behind the drum axis line.
On the +Y side frame only, weld the pawl brackets (6 mm plate): one on the post and one on the front brace, each with a 12 mm pin standing out, 300 mm up, 115 mm behind and 115 mm in front of the drum axis. On the -Y side frame only, weld two guard tabs on the post at 430 and 700 mm up.
Drill the bolt holes across each side frame, through both walls: two 11 mm holes in the rail 20 mm up, 335 and 405 mm in front of the axis; two more 385 and 455 mm behind it; two 11 mm holes in the post, 683 and 757 mm up; two 13 mm holes in the rear brace, 40 mm either side of where its centre line passes 200 mm up. Drill these with the cross members clamped in place (section 3.2) so the holes line up.
Drill the bearing pad for two M14 bolts at 121 mm centres and the top plate for two M12 bolts at 105 mm centres.

How it fits the parts next to it. The cross members bolt to its inside face (Figure 4); the drum bearings bolt on the pads (Figure 6); the crank bearings bolt on the top plates; the pawls hang on the pins (Figure 10).
Check before moving on. Each side frame lies flat within 2 mm; the pad and top plate are level; each side frame weighs about 9.5 kg.

### 3.2 Frame cross members

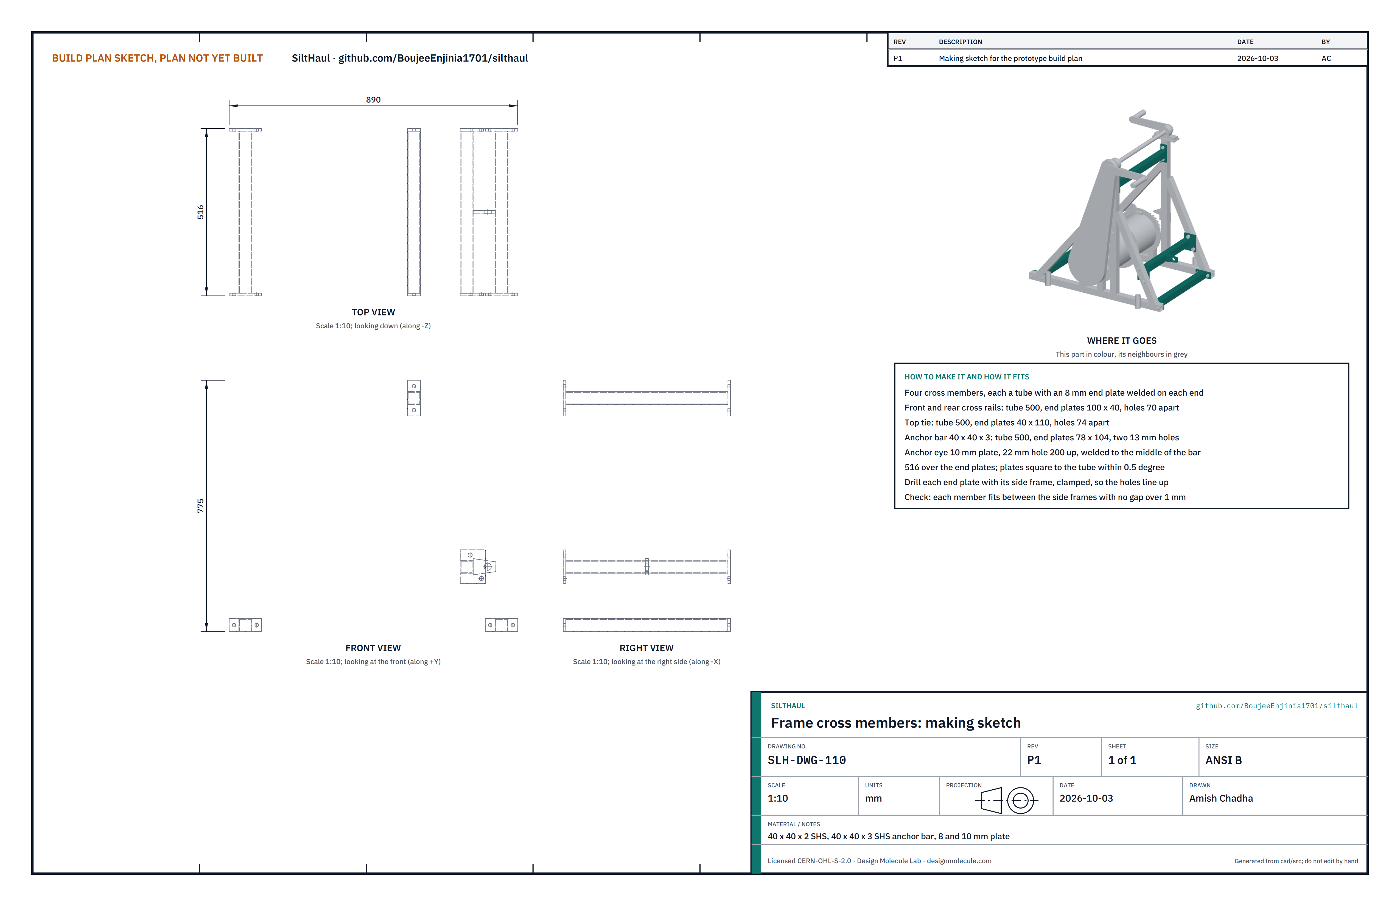
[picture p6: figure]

Figure 3. Frame cross members making sketch (SLH-DWG-110).

5.

6.

7.

8.

What it is and what it is made from. Four members that hold the two side frames 556 mm apart, centre to centre: the front and rear cross rails on the ground, the top tie between the posts and the anchor bar between the rear braces, which carries the sling eye. 40 x 40 x 2 mm tube; 40 x 40 x 3 mm tube for the anchor bar; 8 mm plate for the end plates; 10 mm plate for the anchor eye.
How to make it.
Cut three tubes 500 mm long from 40 x 40 x 2 tube and one from 40 x 40 x 3 tube for the anchor bar.
Cut eight end plates from 8 mm plate: four 100 x 40 for the cross rails, two 40 x 110 for the top tie and two 78 x 104 for the anchor bar.
Weld an end plate square to each end of each tube, so each member is 516 mm over its end plates. On the cross rails the plate sticks out 30 mm each side of the tube; on the top tie it sticks out 35 mm above and below; on the anchor bar it sticks out toward the rear, where the brace is.
Weld the anchor eye (10 mm plate, 22 mm hole) to the middle of the anchor bar, pointing back, its hole 200 mm up when the bar is in place.
Stand the two side frames on a flat floor, clamp each member in place between them and drill through end plate and side frame together (section 3.1, step 7).
Paint each member's ends and the matching place on the side frames the same colour.

How it fits the parts next to it.

1.
2.

3.

4.

5.

6.

Figure 4. Joint 9. The end plate sits flat against the inside face of the side rail; two M10 bolts pass through the plate and both walls of the rail, heads inside and nyloc nuts outside. The top tie bolts the same way to the posts; the anchor bar uses two M12 bolts through each rear brace.
Check before moving on. Bolted up dry, the frame stands without rocking, its base diagonals agree within 3 mm, and both bearing pads are level and in line within 1 mm.

### 3.3 Winding drum

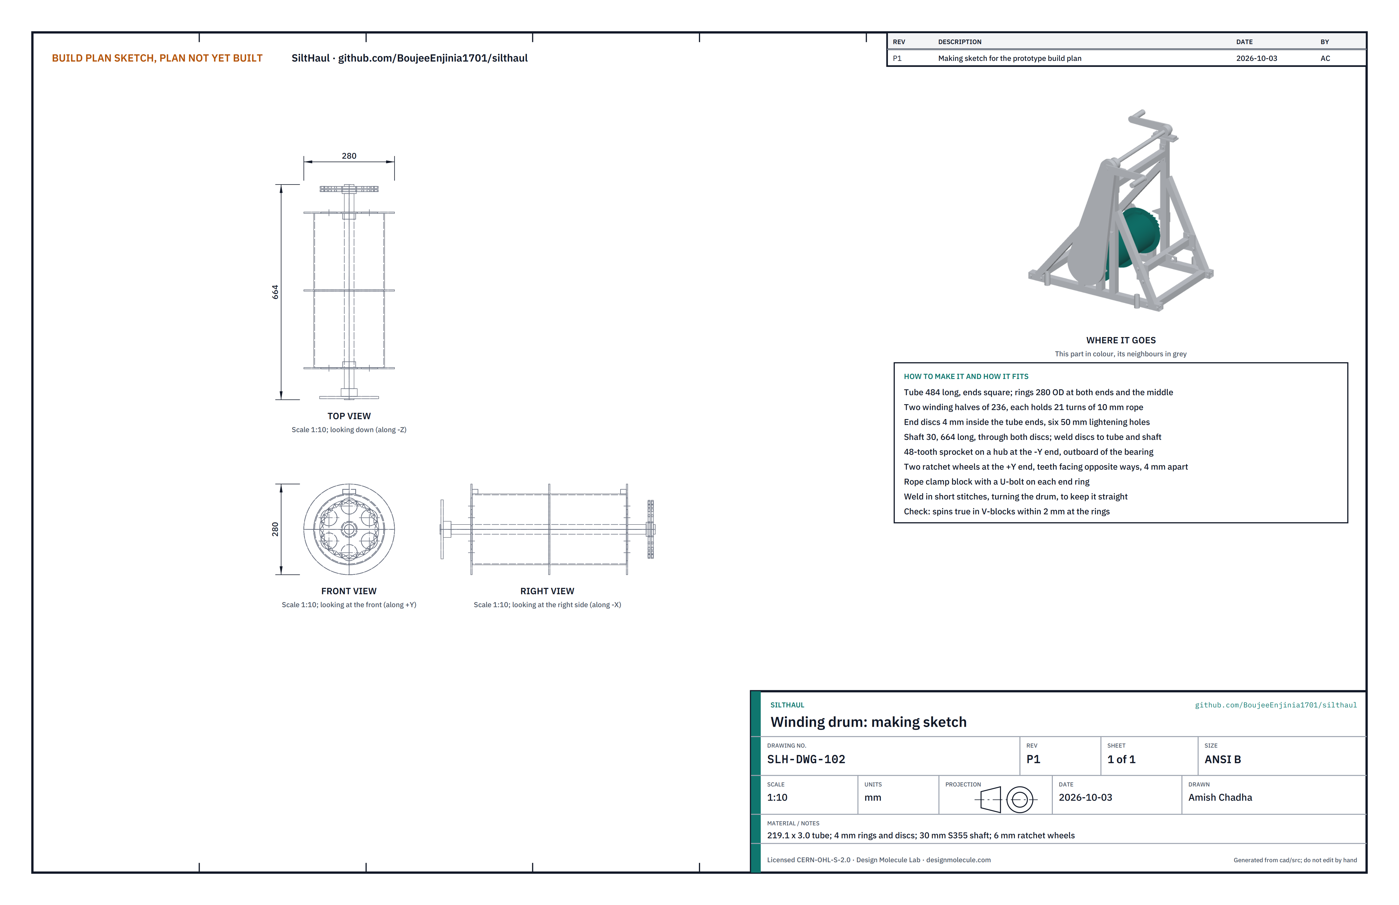
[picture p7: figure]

Figure 5. Winding drum making sketch (SLH-DWG-102).
What it is and what it is made from. The drum that winds the ropes, with the big sprocket and both ratchet wheels on its shaft. 219.1 x 3.0 mm steel tube; 4 mm plate; 30 mm bright steel bar (S355 or EN8); 6 mm plate for the ratchet wheels; the bought 48-tooth sprocket.
How to make it.
Cut the tube 484 mm long with square ends.
Cut two end discs 213 mm across from 4 mm plate with a 30 mm centre hole and six 50 mm lightening holes on a 144 mm circle. Cut three rings 280 mm outside, 219 mm inside, from 4 mm plate.
Push the shaft (671 mm long) through both discs; set the discs flush inside the tube ends; check the shaft is central within 0.5 mm; weld the discs to the shaft and the tube in short stitches, turning as you go.
Weld a ring at each end and one in the middle; each half between rings is 236 mm, room for 21 turns of rope. At the -Y end, weld the big sprocket to a short hub on the shaft, outboard of where the bearing will sit (Figure 13).

1.
2.

3.

4.
5.

At the +Y end, slide on a collar, ratchet wheel 1, a 4 mm spacer and ratchet wheel 2, teeth facing opposite ways as in Figure 10, and weld each to the shaft.
Bolt a rope clamp block with a U-bolt to each end ring.

How it fits the parts next to it. The shaft runs in the two drum bearings (Figure 6). The pull rope winds from below on the -Y half; the return rope winds from above on the +Y half.
Check before moving on. Turned in V-blocks, the rings run true within 2 mm; the sprocket within 1 mm.

### 3.4 Drum bearings (bought)

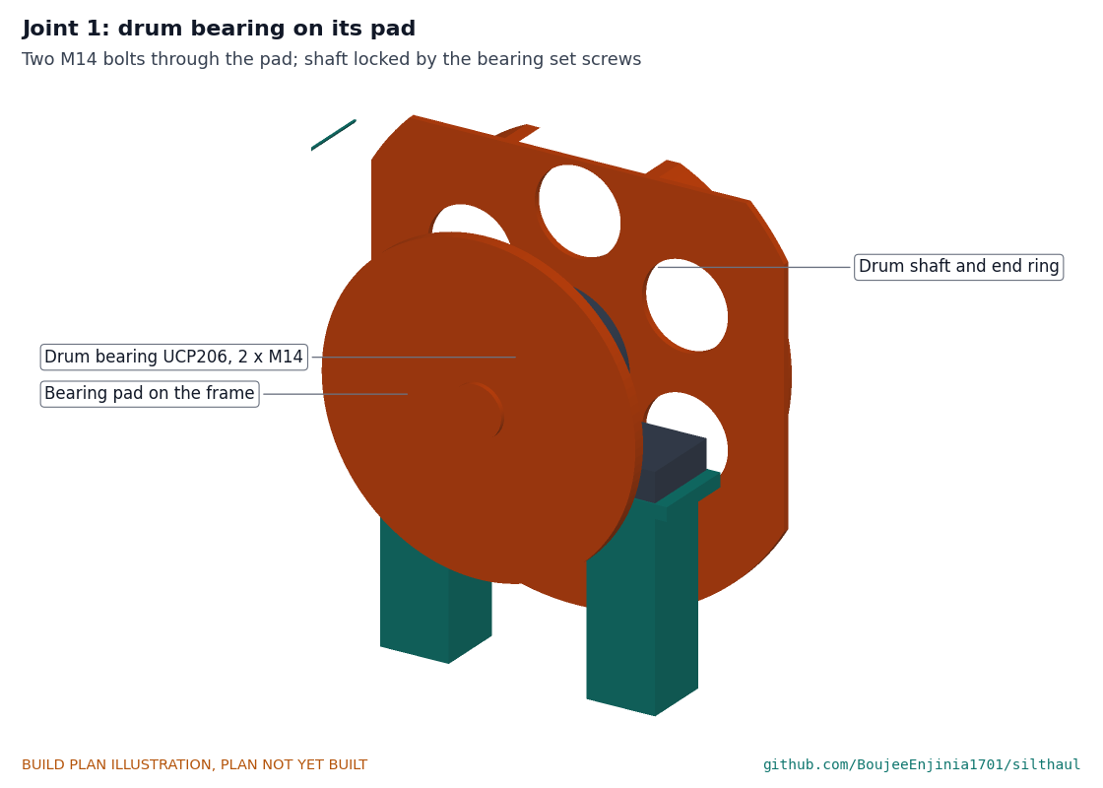
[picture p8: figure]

Figure 6. Joint 1. Each UCP206 bearing bolts to its pad with two M14 bolts; its set screws lock the shaft. Buy two UCP206 pillow block bearings with 30 mm bores. Nothing to make.

6.

7.

### 3.5 Pawls

Figure 7. Pawls making sketch (SLH-DWG-103).
What it is and what it is made from. Two pawls that stop the drum turning back, one for each direction. 8 mm steel plate, profile cut.
How to make it. Cut both from the sketch: a 12 mm pivot hole, a nose with a 2.5 mm radius 85 mm from the drum axis when hanging, and a thumb tab. Deburr; the nose edge stays square.
How it fits the parts next to it. Each hangs on its pin in the plane of its own ratchet wheel, held by a washer and an R-clip (Figure 10). To choose the direction held, flip the other pawl up onto its stop.
Check before moving on. Each falls into every tooth gap by its own weight as the drum is turned slowly.

### 3.6 Crank shaft, sprocket hub and cranks

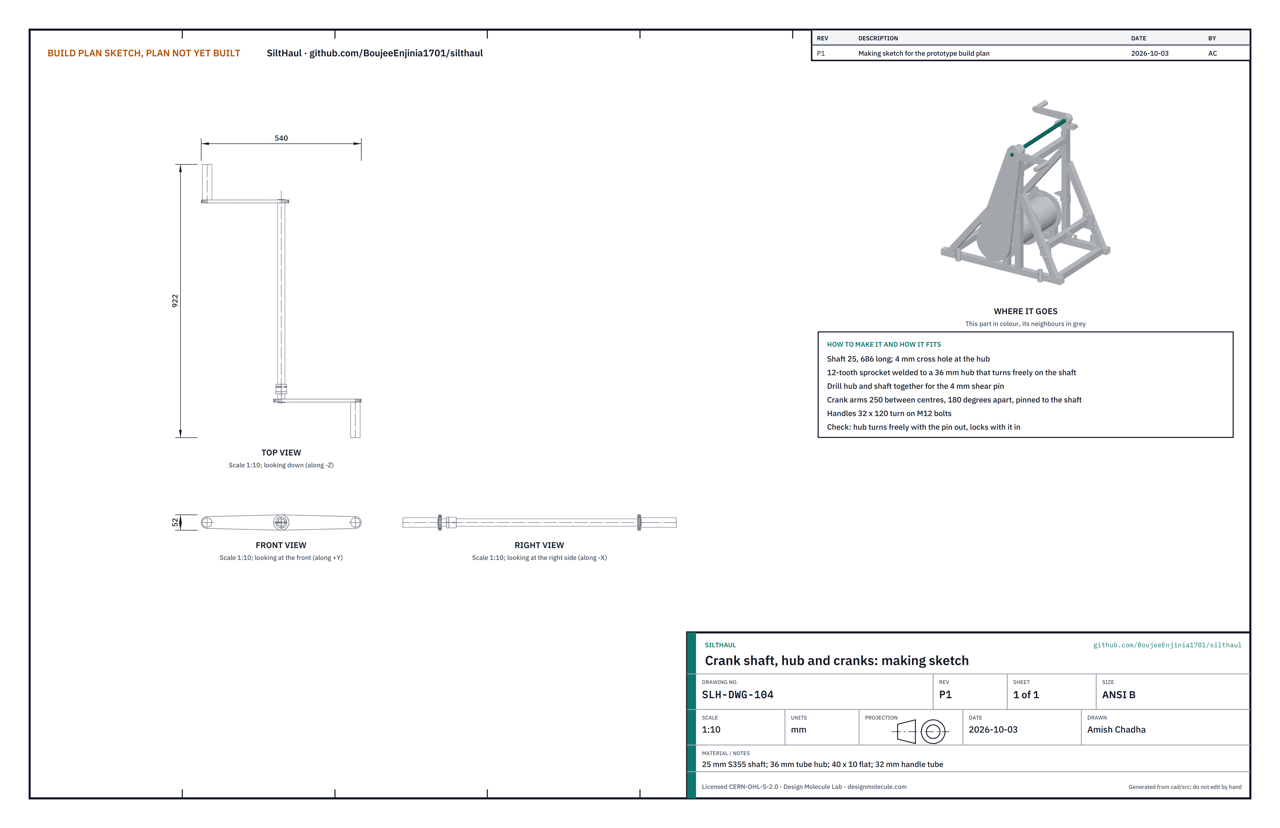
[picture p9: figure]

Figure 8. Crank shaft, hub and cranks making sketch (SLH-DWG-104).
What it is and what it is made from. The shaft the people turn, and the hub that drives the chain through the shear pin. 25 mm bright steel bar; 36 mm tube for the hub; the bought 12-tooth sprocket; 40 x 10 mm flat bar; 32 mm tube; M12 bolts.
How to make it.
Cut the shaft 689 mm long.
Cut the hub 25 mm long from 36 mm tube bored to slide on the shaft; weld the 12-tooth sprocket to its outer end.
Slide the hub on the shaft at the -Y end, clamp, and drill a 4 mm hole through hub and shaft together, square to the shaft.
Make two crank arms 250 mm between hole centres; bore one end for the shaft and drill the other for an M12 handle bolt. Pin each arm to the shaft with a 6 mm roll pin, the two arms 180 degrees apart.
Fit a 32 mm handle tube, 120 long, on each M12 bolt so it turns freely.

How it fits the parts next to it.

1.
2.

3.

4.

5.

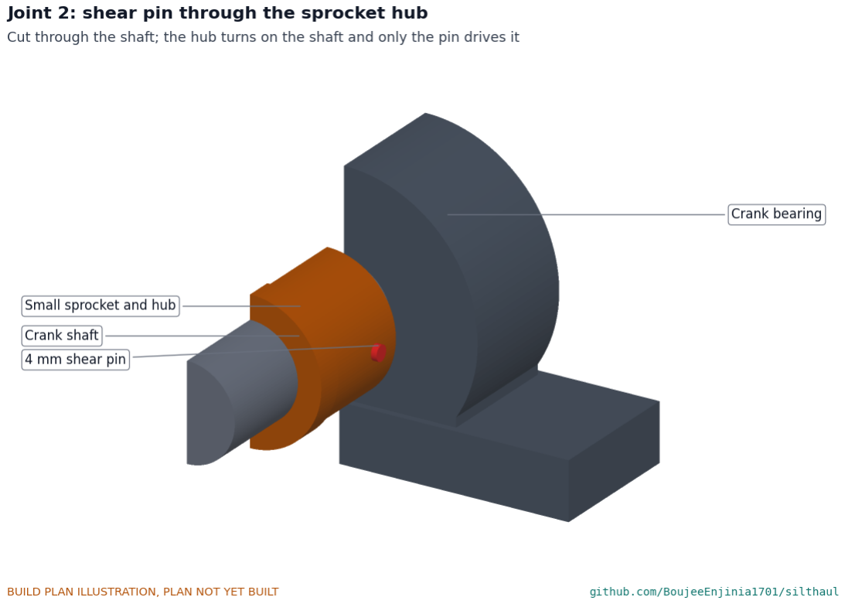
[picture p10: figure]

Figure 9. Joint 2. The hub turns freely on the shaft; only the 4 mm pin passes the drive. If the rope tension passes about 2.5 kN, the pin shears and the cranks spin free while a pawl holds the drum.
Check before moving on. With the pin out the hub turns freely by hand; with it in, it does not move.

### 3.7 Ratchet wheels and pawls together

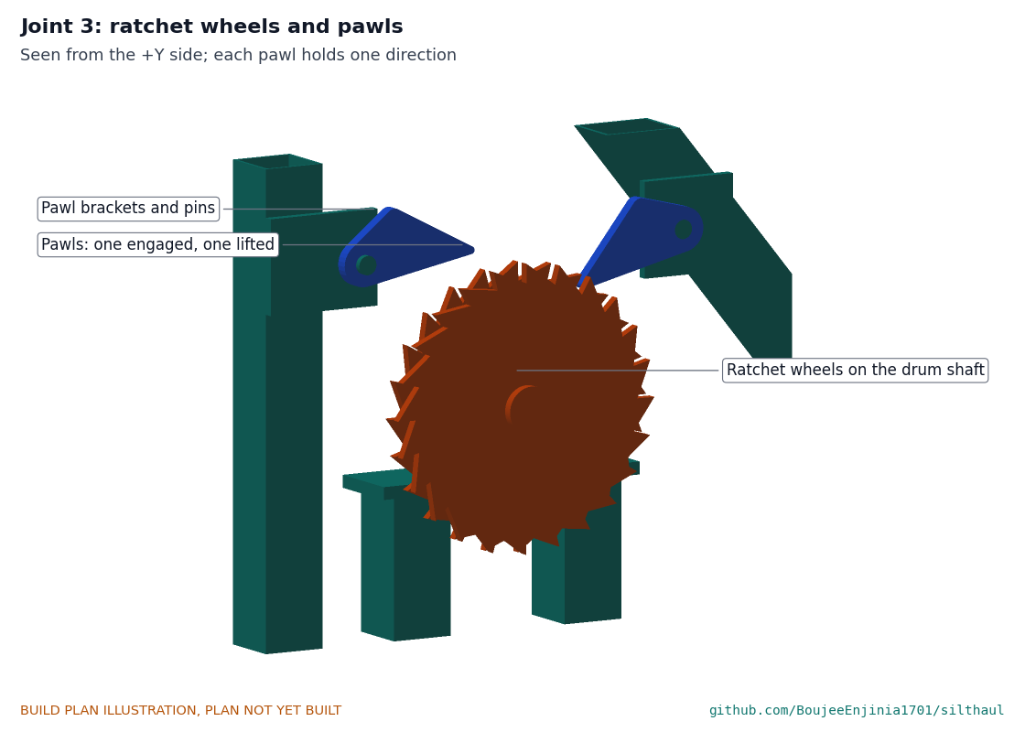
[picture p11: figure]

Figure 10. Joint 3. The two ratchet wheels face opposite ways; the pawl in front holds one, the pawl behind holds the other. Here one is down and one is lifted.

### 3.8 Anchor eye and sling

Figure 11. Joint 4. The bow shackle's 19 mm pin goes through the 22 mm hole in the eye; the round sling sits in the bow. The pull is 200 mm up, in line with the ropes.

### 3.9 Chain guard

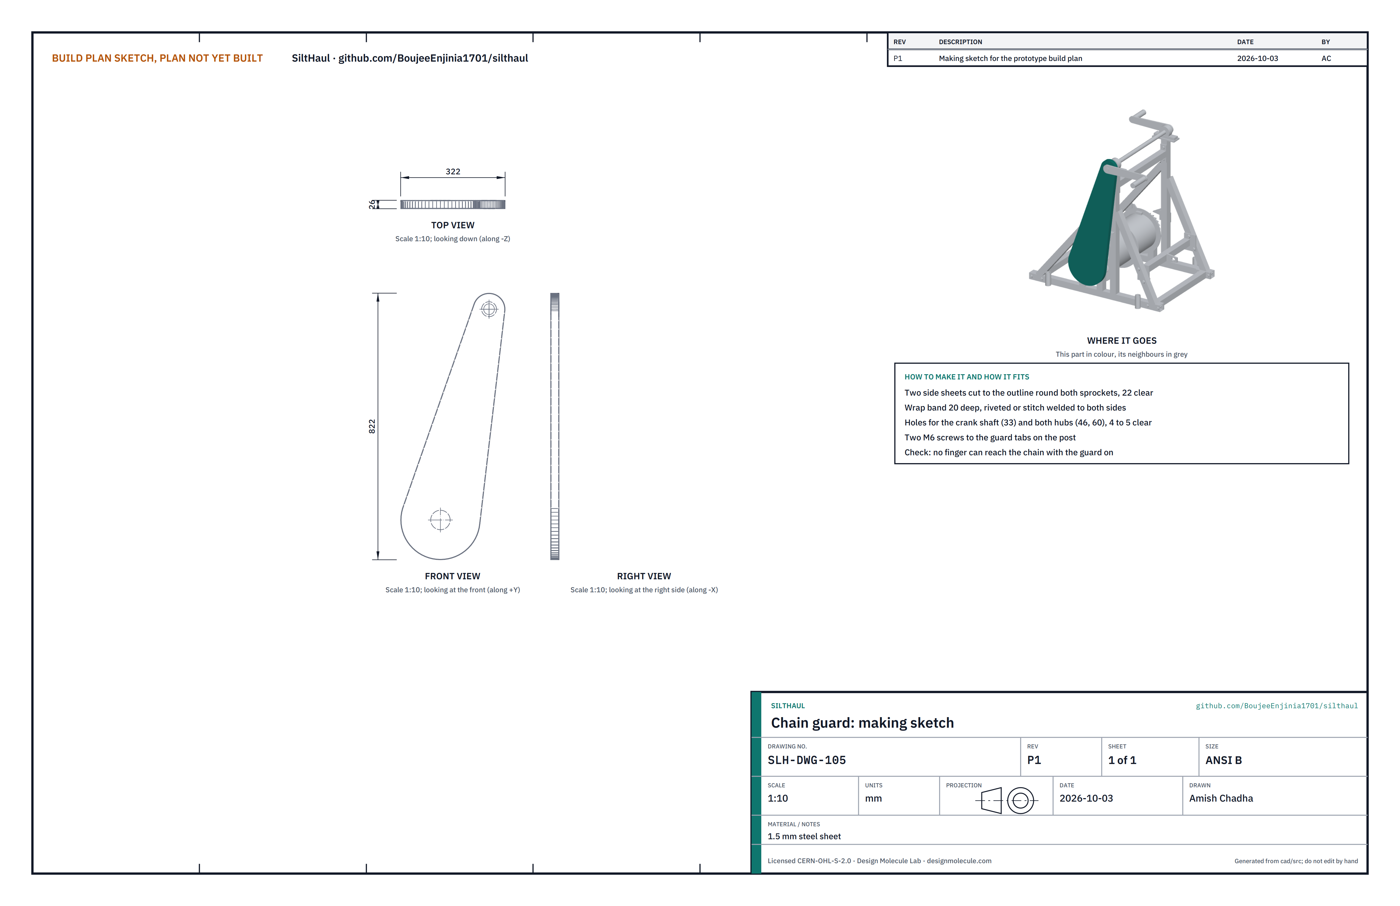
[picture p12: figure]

Figure 12. Chain guard making sketch (SLH-DWG-105).
What it is and what it is made from. A closed box round the chain and both sprockets. 1.5 mm steel sheet.
How to make it.
Mark both side sheets from the sketch: the outline round both sprockets with 22 mm clearance.
Cut the holes in the inner sheet for both hubs and in the outer sheet for the crank shaft, each 4 to 5 mm clear. Bend a band 20 mm wide round the outline and stitch weld or rivet both sheets to it.
Drill for two M6 screws to match the guard tabs.

How it fits the parts next to it.

1.
2.
3.
4.

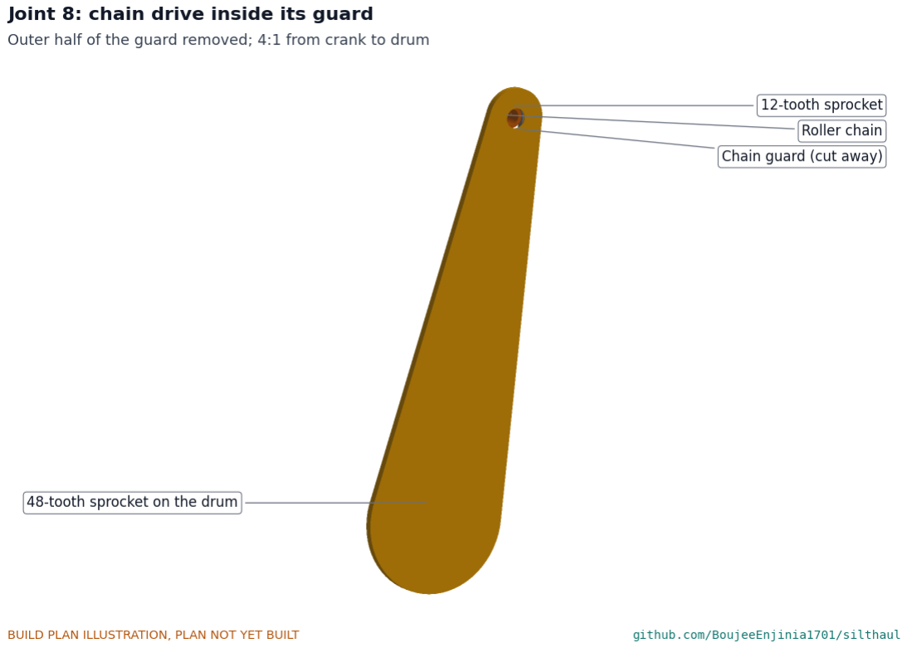
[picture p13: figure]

Figure 13. Joint 8, outer half of the guard removed. The chain runs 4:1 from the small sprocket on the crank shaft to the big sprocket on the drum.
Check before moving on. With the guard on, a finger cannot reach the chain or sprockets through any gap.

### 3.10 Ground stakes (make 4)

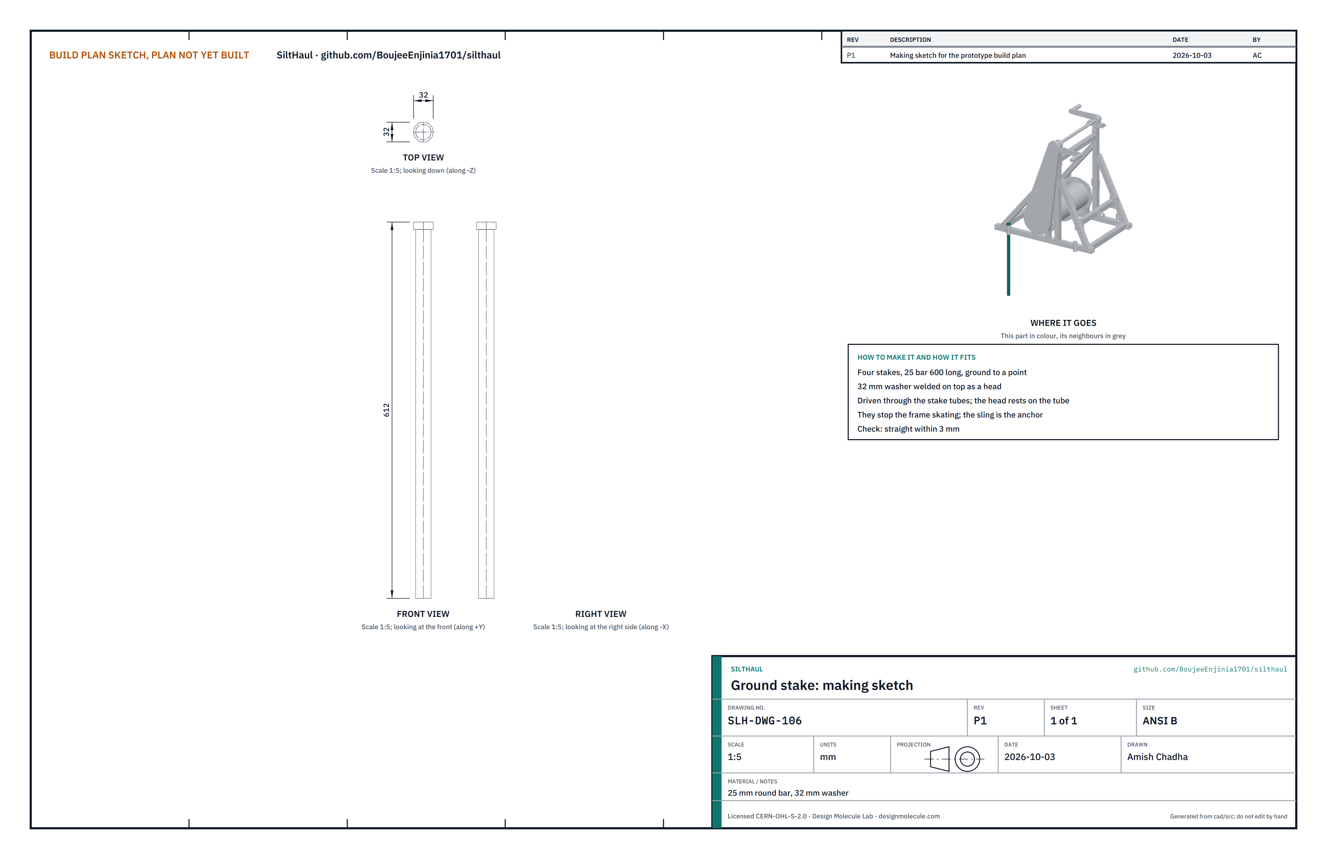
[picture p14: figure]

Figure 14. Ground stake making sketch (SLH-DWG-106).
What it is and what it is made from. Pins that stop the capstan skating sideways. 25 mm round bar 600 long; a 32 mm washer.
How to make it. Grind one end to a point; weld the washer on the other end as a head.
How it fits the parts next to it. Each is driven through a stake tube until its head rests on the tube. The stakes are not the anchor; the sling is.
Check before moving on. Straight within 3 mm.

### 3.11 Scraper boxes (make 2) and tipping bar

Figure 15. Scraper box making sketch (SLH-DWG-107). Make two the same.
What it is and what it is made from. The boxes that carry the mud, one on each rope. Each: 2 mm steel sheet; 8 x 50 and 8 x 25 mm flat bar; 10 mm plate; 33.7 x 3.2 mm tube. One 26.9 x 2.6 mm tube 900 long for the tipping bar, shared by both boxes.
How to make it. For each box:
Cut the floor 735 x 210, the sloped back 301 x 210 and two sides with a sloping rear edge (845 long at the top, 735 at the floor line plus the 110 mm slope, 280 high).
Tack the floor, back and sides together on a flat table; the back leans out 110 mm over its 280 mm height; weld inside and out.
Weld the two skids (8 x 25 bar) under the floor, 160 mm apart, their rear ends cut at 45 degrees.
Weld the lip (8 x 50 bar, the full width) to the front of the floor at about 20 degrees down, and grind its front edge to a bevel that touches the ground.
Weld two bridle lugs (10 mm plate, 19 mm hole 75 mm up) on the outside of each side: at the front, the hole 10 mm ahead of the lip line; at the rear, the hole 55 mm from the back's top edge, behind the sloped back.
Weld the socket tube (150 long) to the middle of the back, pointing up and back at 45 degrees, meeting the back 65 mm below its top edge.
Cap both ends of the tipping bar.

The box is narrow so that the two boxes, on rope lines 300 mm apart, pass each other 42 mm apart in the room and both run over the ramp inside its cheeks.

1.

2.

3.
4.

5.

6.

7.

How it fits the parts next to it.

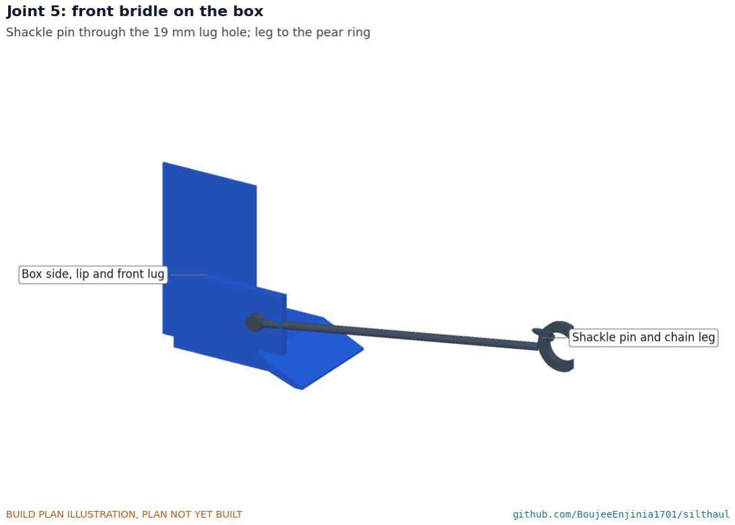
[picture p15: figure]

Figure 16. Joint 5. A bow shackle's pin goes through each front lug; a leg of 8 mm chain runs from each shackle to a pear ring 300 mm ahead. The rear bridle is the same, behind the box.
Check before moving on. 40 L of water poured in comes to about 245 mm deep (cover the open front with a board); each box sits flat on its skids and measures 258 mm over its shackle pins.

### 3.12 Tail plate, pins and keeper

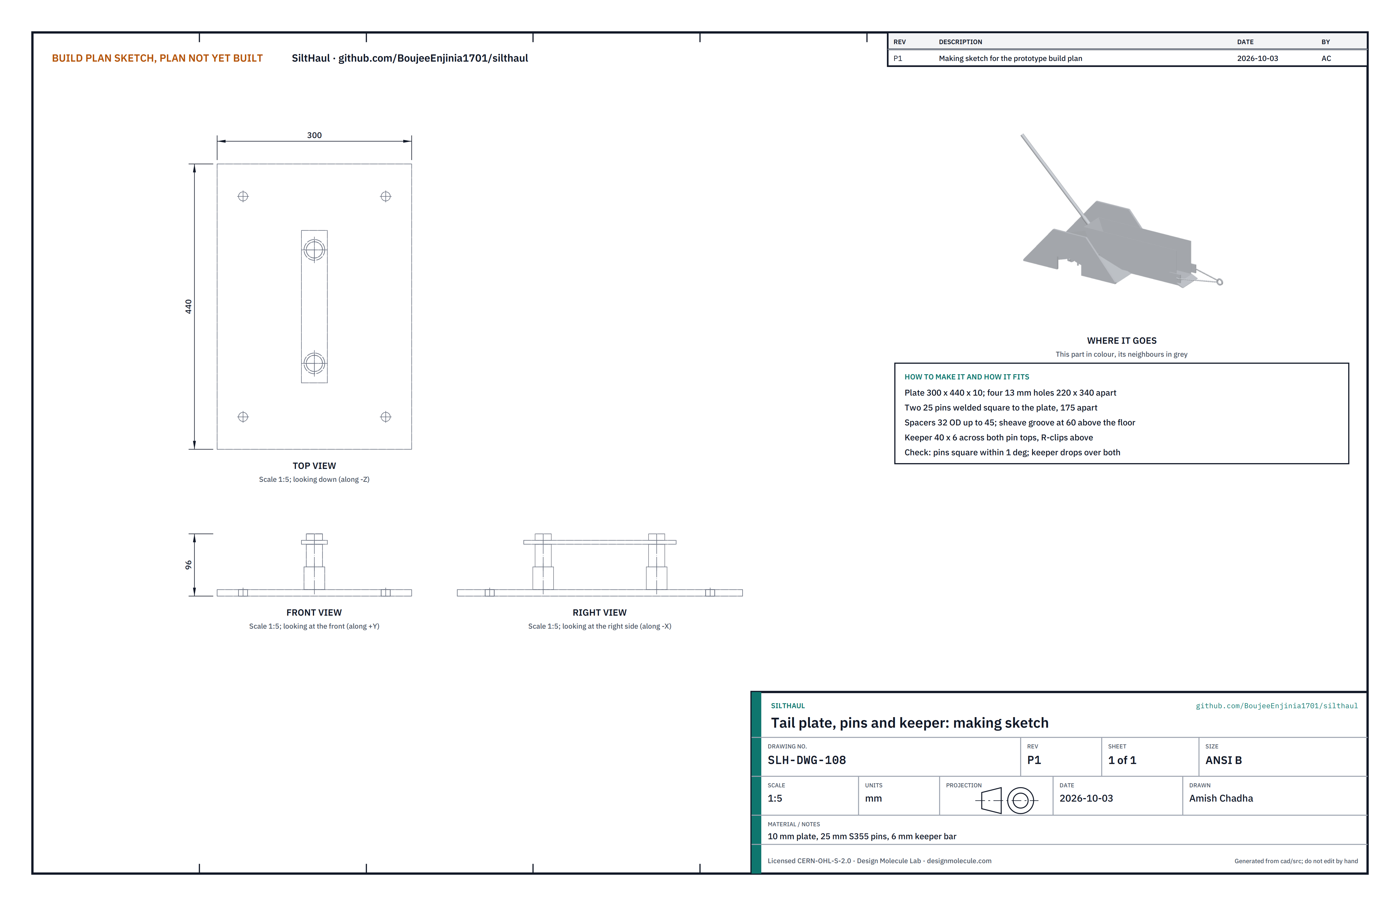
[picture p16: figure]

Figure 17. Tail plate, pins and keeper making sketch (SLH-DWG-108).
What it is and what it is made from. The block at the far end of the room that turns the rope back. 10 mm plate 300 x 440; 25 mm bright steel bar (S355); 32 mm tube; 6 x 40 mm flat bar.
How to make it.
Cut the plate; drill four 13 mm anchor holes at the corners of a 220 x 340 rectangle.
Drill two 25 mm holes on the plate's centre line across, 175 mm apart; push in the pins (85 mm long), check square, and weld above and below.
Cut two spacers 35 mm long from 32 mm tube.
Cut the keeper bar 255 long, drill two 25 mm holes 175 apart, and drill each pin top for an R-clip.

How it fits the parts next to it.

1.
2.

3.
4.

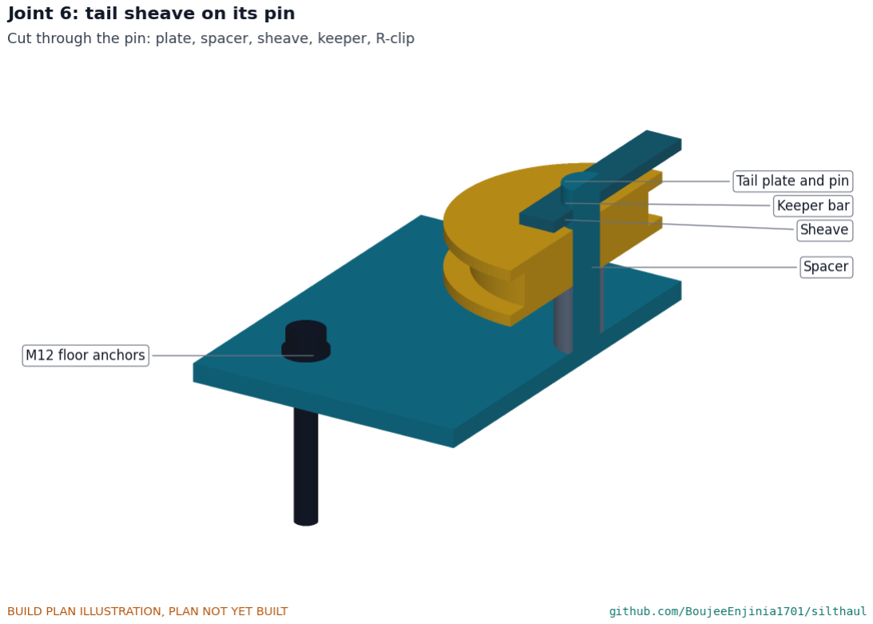
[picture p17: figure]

Figure 18. Joint 6, cut through a pin. Plate, spacer, sheave, keeper bar and R-clip stack on the pin; the rope groove sits 60 mm above the floor. M12 anchors pass through the plate into the slab.
Check before moving on. Pins square within 1 degree; the keeper drops over both pins; each sheave turns freely.

### 3.13 Doorway ramp

Figure 19. Doorway ramp making sketch (SLH-DWG-109).
What it is and what it is made from. A ramp that carries both boxes and the ropes over the threshold and keeps the ropes off the door frame. 18 mm exterior plywood; 3 mm steel sheet; 60.3 x 3.6 mm tube; 20 mm bar; two nylon bushes; M8 bolts.
How to make it.
Cut two cheeks from plywood: 840 long, rising to 330 high over the middle 300, with a notch 220 wide and 110 high underneath for the threshold. Drill a 21 mm hole 110 mm up at the middle.
Cut and fold two deck trays from 3 mm sheet: 610 wide, each running from the floor to 130 mm up over 380 mm, with 30 mm flanges turned down each side.
Cut the roller 600 long; press a nylon bush into each end.
Bolt the flanges through the cheeks with M8 bolts; the deck tops meet the floor in a thin edge and stop 40 mm short of the middle.
Push the axle through one cheek, the roller and the other cheek; R-clip both ends.

How it fits the parts next to it.

1.

2.

3.
4.

5.

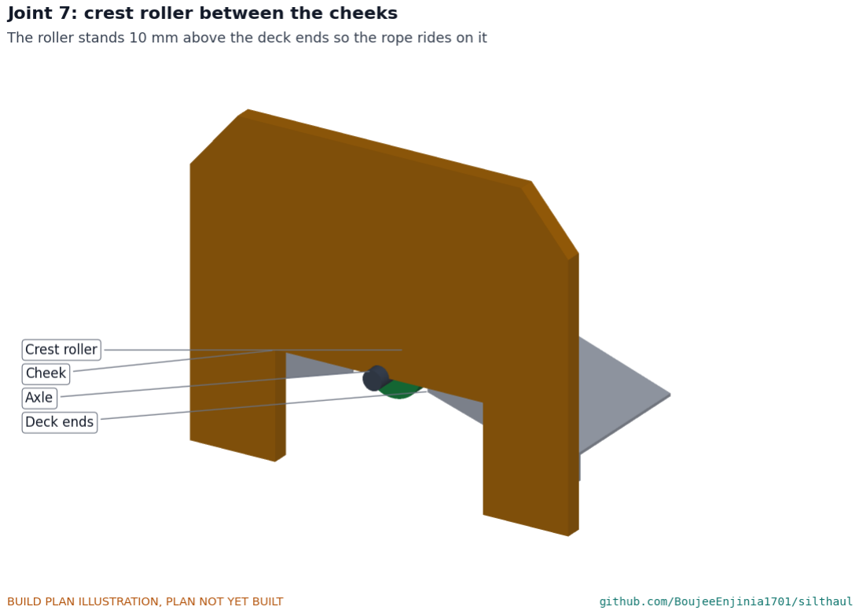
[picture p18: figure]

Figure 20. Joint 7. The roller stands 10 mm above the deck ends, so the ropes and the boxes ride over it rather than over the edges.
Check before moving on. 646 mm outside; the roller turns by hand; the ramp sits flat over a 110 mm threshold; set in the doorway, its middle lies midway between the two rope lines, so each box runs 26 mm inside a cheek.

### 3.14 Bought components

Buy to specification, not brand. Line numbers are those of the bill of materials.
Bearings (lines 3 and 4). Two UCP206 (30 mm) and two UCP205 (25 mm) pillow block ball bearings. Sprockets and chain (lines 6 and 7). ISO 08B-1 (12.7 mm pitch): a 12-tooth sprocket bored to suit the hub and a 48-tooth plate wheel bored 30 mm; 1.75 m of chain with breaking load at least 17.8 kN and one connecting link.
Shear pins (line 10). 4 mm S235 mild steel bar cut 44 mm long, with split pins; never hardened steel.
Sling and shackles (lines 12 and 20). A 3 m polyester round sling, WLL 2,000 kg; ten bow shackles WLL 1,000 kg with 19 mm pins (two for the sling, four for each box); a tree protector strap; 4.8 m of 8 mm grade 30 chain; four 56 mm pear rings.
Tail sheaves (line 14). Two steel sheaves, 125 mm pitch diameter for 10 to 12 mm fibre rope, 25 mm bore, rated at least 1,000 kg.
Floor anchors (line 15). M12 wedge anchors for sound concrete, 80 mm embedment; ten, so six are spare.

•
•

•
•

•

•

Rope (line 16). 62 m of 10 mm polyester double braid, minimum breaking strength at least 18 kN, cut into a 17 m pull rope, a 17 m return rope and three tail ropes of 12.5, 9 and 6 m, each with an eye splice at both ends. Fasteners and consumables (lines 21 and 23). Four M14 x 50 and four M12 x 45 bolts for the bearings; eight M10 x 70 and four M12 x 70 bolts with nyloc nuts and washers for the frame; M6 screws, M8 bolts for the ramp, R-clips; primer, paint, welding wire and discs.
Stop signal and briefing card (line 22). A laminated card with the hand signals and stop rule, two whistles and two armbands.

### 4. Putting it together

In each picture the parts already fitted are grey and the part being fitted is in colour, with an arrow showing the way it goes in. Steps 1 to 9 are done in the workshop for a trial assembly and repeated on site; steps 10 to 13 are done on site only. Two people throughout.

Step 1: bolt the frame together

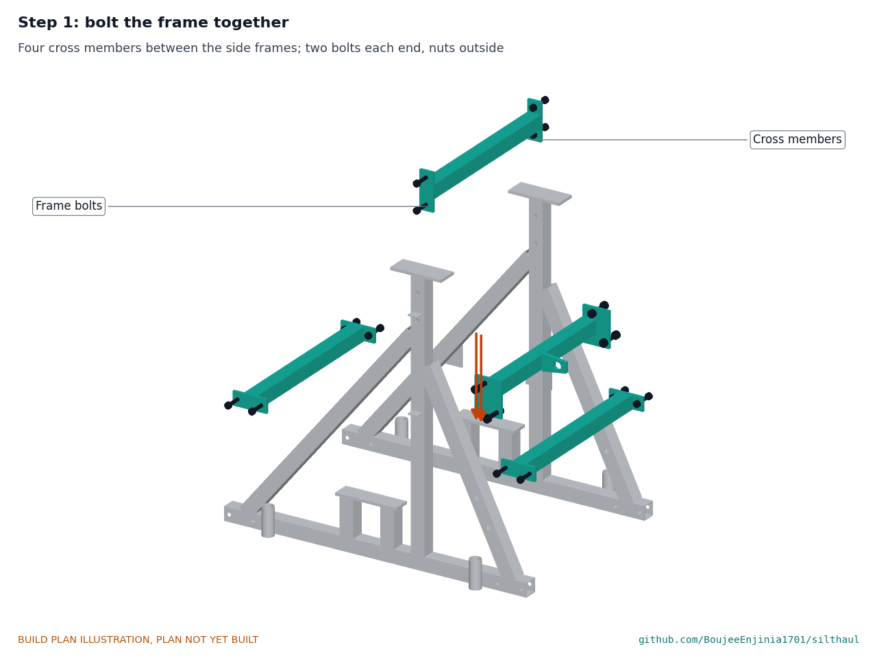
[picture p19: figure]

Stand the two side frames upright, ratchet side (+Y) on the right when you look from the front. Fit the front and rear cross rails, the top tie and the anchor bar between them, matching the paint marks. Two bolts at each end, heads inside, washers and nyloc nuts outside: M10 for the rails and the tie, M12 for the anchor bar. Tighten firmly; check the base diagonals agree within 3 mm.

•

•

•

Step 2: drum bearings onto the drum shaft

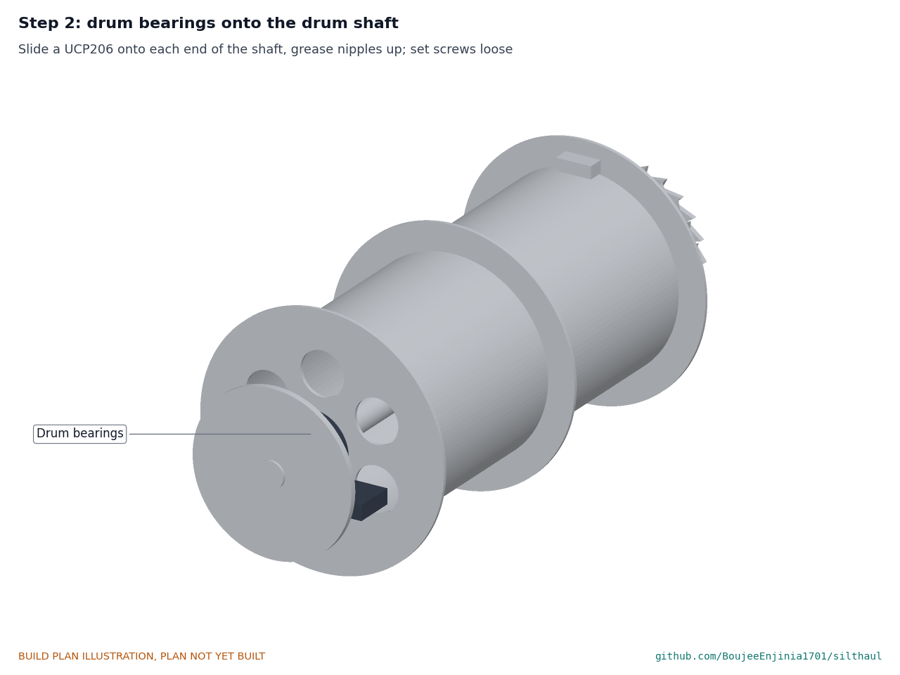
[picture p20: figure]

Slide a UCP206 bearing onto each end of the drum shaft, grease nipple up, set screws loose. The drum lifts with its bearings: 23 kg.

Step 3: lower the drum onto the pads

Two people lower the drum and bearings onto the pads, sprocket to the -Y side. Bolt each bearing with two M14 bolts; centre the drum between the frame sides; tighten the set screws.

Step 4: crank shaft, hub and bearings onto the top plates

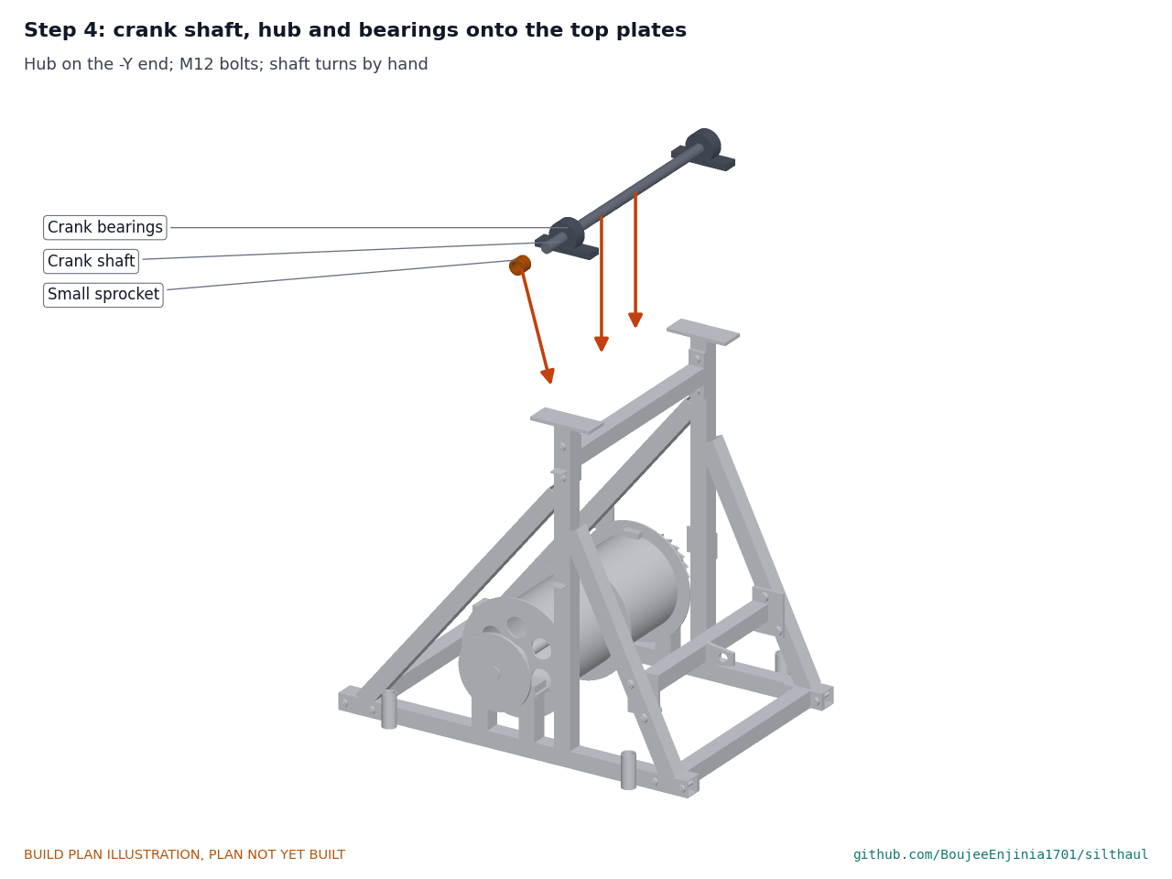
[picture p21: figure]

Slide the crank bearings onto the crank shaft, with the sprocket hub on the -Y end. Bolt the bearings to the top plates with M12 bolts, the small sprocket in line with the big one within 1 mm.

Step 5: fit the chain

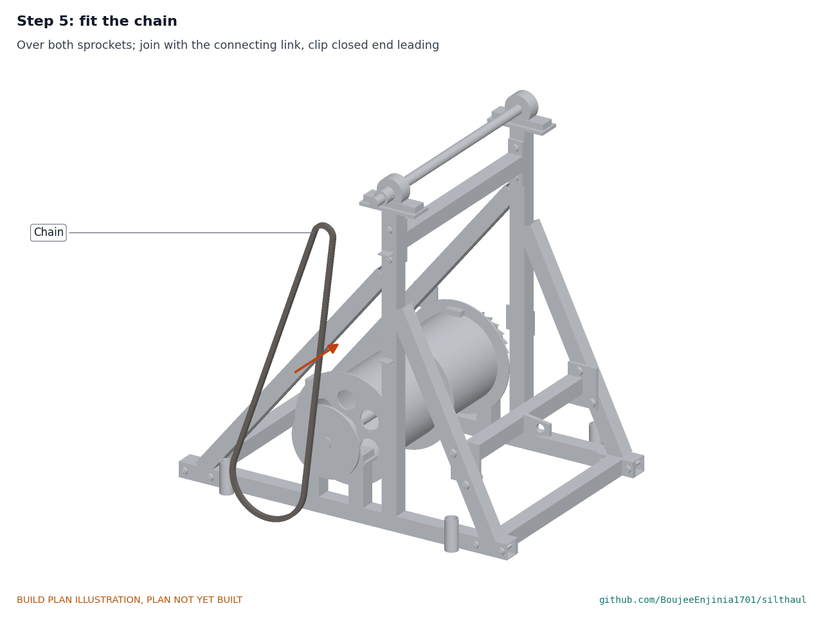
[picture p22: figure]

Lay the chain over both sprockets and join it with the connecting link, the clip's closed end leading in the haul direction. The chain should lift about 10 mm at mid-span by hand.

Step 6: fit the shear pin

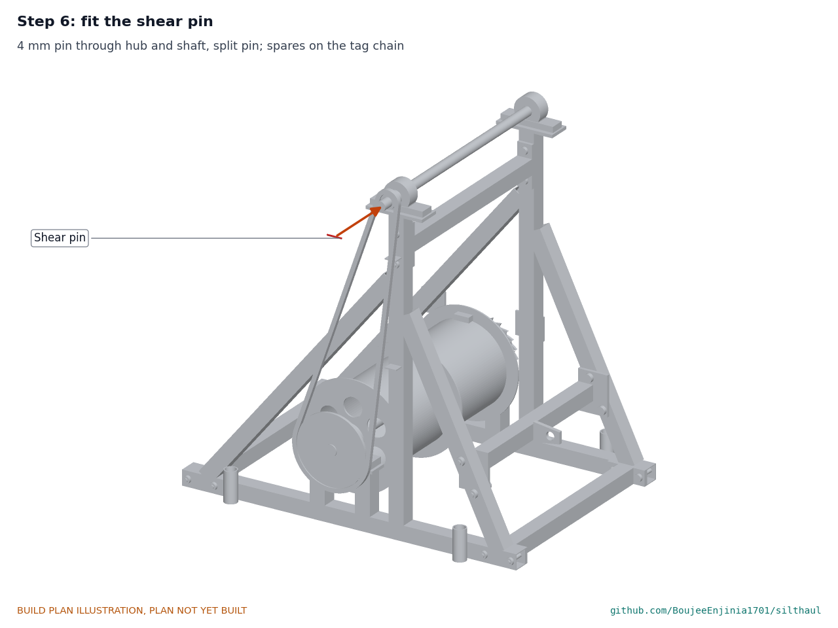
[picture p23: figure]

Push a 4 mm shear pin through the hub and shaft and fit its split pin. Hang the spares on the tag chain at the capstan.

Step 7: chain guard on

Fit the guard over the chain and fix it with two M6 screws to the tabs. From now on, the cranks are never turned with it off.

Step 8: cranks on

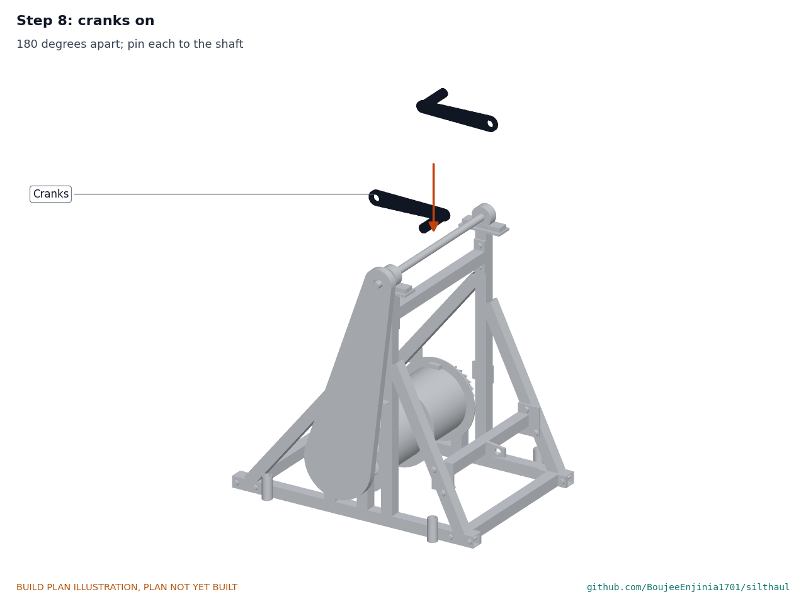
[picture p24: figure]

Fit a crank arm to each end of the crank shaft, 180 degrees apart, and roll-pin each.

Step 9: pawls on their pins

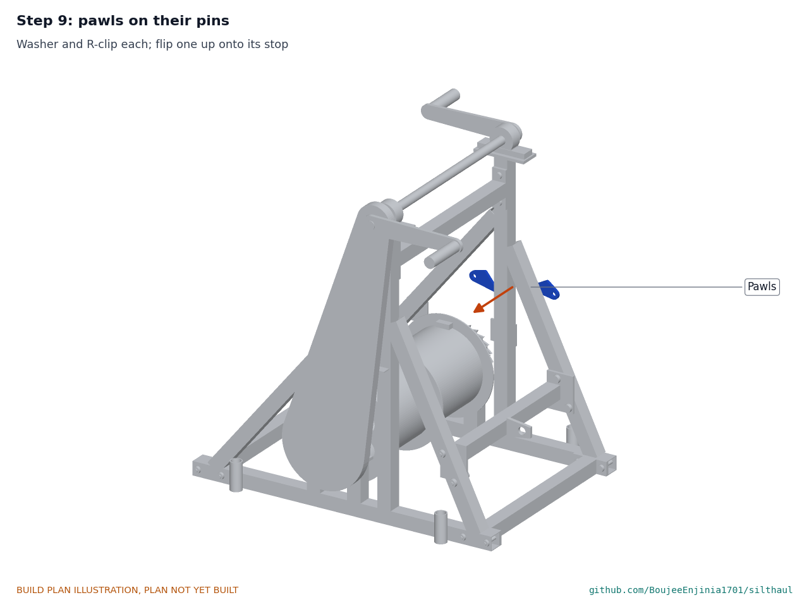
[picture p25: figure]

Hang each pawl on its pin with a washer and an R-clip. Flip one up onto its stop.

Step 10: set the capstan, stakes and sling

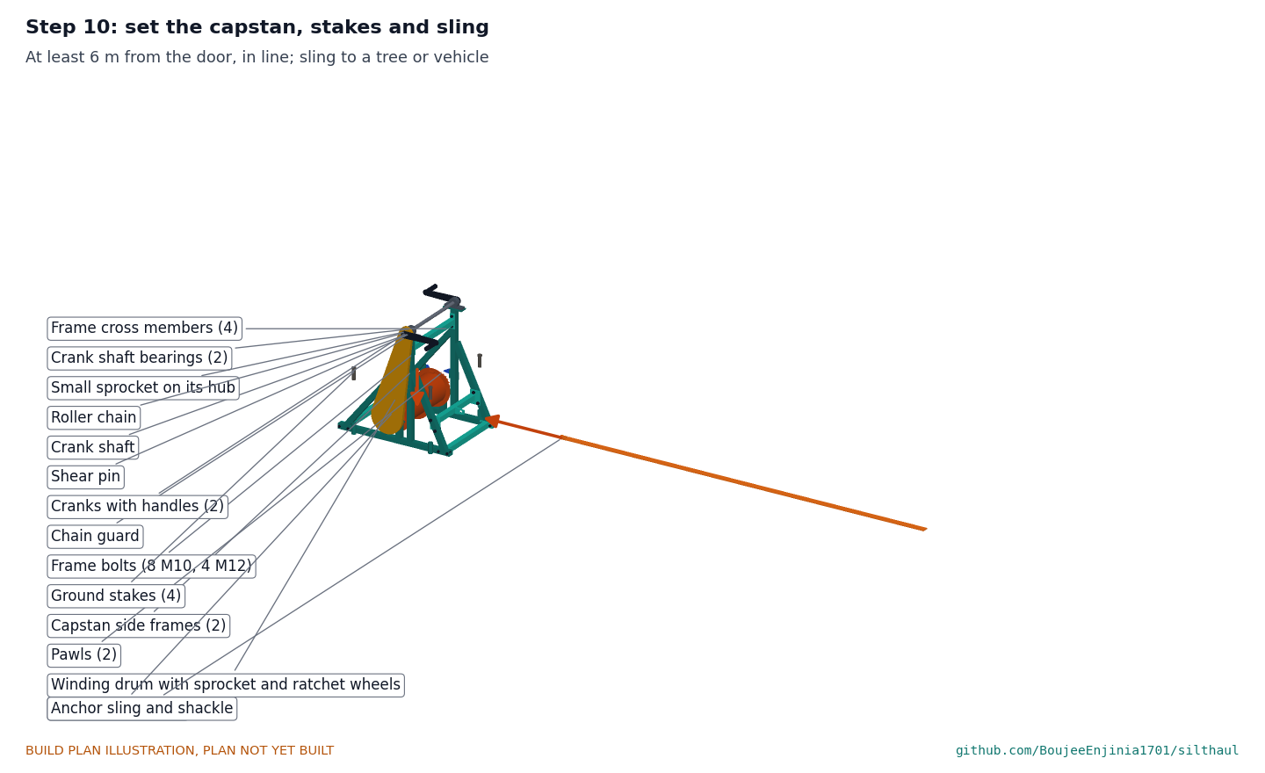
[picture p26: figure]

For carrying, the capstan comes apart into the two side frames, the four cross members, the drum with its bearings and the crank shaft with its cranks; the frame pieces lie flat. On site, repeat steps 1 to 9. Set the capstan on firm level ground at least 6 m beyond the door, its drum square to the line from the tail block through the door. Drive the four stakes. Wrap the sling round a sound tree, low on the trunk with the protector, or a parked vehicle's recovery point; shackle it to the eye so it runs level or rises 10 degrees at most.

Step 11: anchor the tail block

At the far end of the room, on the line through the door, check the slab (section 6). Drill four 12 mm holes 80 mm deep through the plate holes, clean them, fit the M12 anchors and tighten to the maker's torque. Stack spacers, sheaves and keeper on the pins; R-clip.

Step 12: ramp across the threshold

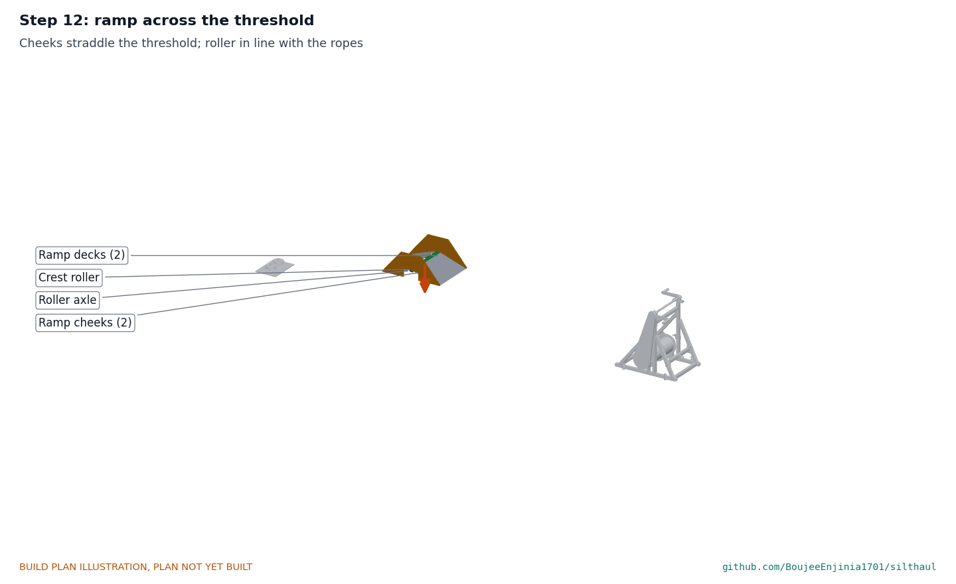
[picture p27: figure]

Stand the ramp in the doorway with its cheeks straddling the threshold, the roller square to the rope line and the ramp's middle midway between the two rope lines.

Step 13: reeve the ropes and shackle both boxes


Choose the tail rope for the room: the longest of the three (12.5, 9 or 6 m) that is at least 1.5 m longer than the room and at least 2.3 m shorter than the distance from the tail block to the capstan. Set box 1 at the far end of the room on the line through the -Y half of the drum, and box 2 outside, between the ramp and the capstan, on the line through the +Y half, both with their open fronts toward the door. Clamp the pull rope's end to the drum's -Y half, wind on three turns from below, run it over the ramp roller and shackle it to box 1's front bridle ring. Clamp the return rope's end to the +Y half, wind on three turns plus the turns for box 2's distance from the capstan from above, and shackle it to box 2's front bridle ring. Shackle the tail rope to box 1's rear ring, take it round both tail sheaves, back over the ramp roller beside box 1's line, and shackle it to box 2's rear ring. Take up the slack with the cranks until all the ropes are just off the floor.

### 5. First checks

These are listed here and recorded in a TRL 4 test report, not in this plan. Table 2. First checks.

Check | Requirement How | Pass when

Fit through
the door
| R4 | Carry the boxes, tail block and ramp through a 0.7 m opening; haul both boxes over the ramp and past each other in the room | Nothing touches the door frame; the boxes pass without touching
Holding | R12 | At working pull, let go of the cranks in each direction | The drum stops within one tooth; cranks do not kick back past a quarter turn
Shear pin release | R11 | Pull the box against a fixed stop through a load cell, cranking slowly | The pin shears between 1,960 and 2,940 N; a pawl holds the drum
Proof load of anchors | R6, R7 | CalRig or a load cell, held 1 min: tail block to 9.0 kN (both legs at 1.5 times 3,000 N), capstan sling and frame to 4.9 kN | No movement over 2 mm, no damage
Crank force | R2 | Spring balance on a handle with a full box going out and the empty one coming back | 150 N or less per person with two cranking
Box capacity | R3 | Fill each box with 40 L of water, front boarded | Level about 245 mm
Haul trial | R1, R5 | Full length with both boxes, timed against a bucket crew of the same four people | SiltHaul moves at least half as much; nobody lifts or carries mud
Setup | R8 | Three people, timed | 20 min or less
Mass and packing | R9 | Weigh each lift; take the frame apart and pack the whole kit into a small hatchback | Each 25 kg or less; the kit fits a small hatchback with the rear seats folded (R9 as restated)

### 6. Safety stops

Work stops at each of these points until what is listed is true.
Before any rope is put under load. The building has been checked for structural damage and the electricity is off. The chain guard is on. A pawl is down. Everyone has been briefed with the card: one signaller, whistle and hand signals; one blast stops the cranks.
Before fitting the tail block. The slab has been drilled and is sound concrete at least 100 mm thick, with no hollow sound under tiles and no cracks within 150 mm of a hole. If not, SiltHaul is not used in that room.
Before the first haul on a site. Every anchor has been proof-loaded for 1 min at 1.5 times its load at the 3,000 N limit: the tail block to 9.0 kN and the capstan sling and frame to 4.9 kN with nobody in the rope lines. The rope, splices, shackles and sling have been inspected that day.
Before each haul. Nobody is inside the loop, in the line of a rope, beside a sheave or within 2 m of the ramp. Loaders stand to the side away from the other box's line and never between the two boxes: they pass each other 42 mm apart.
Before dumping and filling. The cranks are stopped and a pawl is holding before the crank crew leave the cranks to dump one box and the loaders start filling the other. Two people lift the tipping bar; nobody stands in front of the lip.
After a shear pin breaks. Stop, find the jam with the rope slack, clear it, then fit a new pin of the same 4 mm S235 bar. Never a bolt, a nail or a harder pin.

1.

2.

3.

4.

5.

6.

At the end of each day. Inspect the rope for cuts and glazing, the splices, the shackles, the pawls and the anchors; replace anything damaged.

### 7. Tools, skills and workspace

MIG welder (or a small stick welder with 2.5 mm electrodes) and a person who can weld 2 mm tube without burning through; welding screen, gloves and mask.
Angle grinder with cutting and grinding discs; metal saw; pillar drill with bits to 25 mm; hammer drill with a 12 mm masonry bit for site.
Jigsaw for the plywood; bending brake or a vice and hammer for the 1.5 and 3 mm sheet.
Spanners or sockets for M10 to M14, torque wrench, R-clip pliers, splicing fid if the eye splices are made in-house.
A flat floor or welding table about 1.0 x 1.0 m for the side frames; two people for the drum.
Rope work: eye splices in double braid made by a rigger or a trained person.

### 8. Where the numbers come from

cad/src/model.py : the parametric model, its constructability checks and the STEP and STL files in | cad/step
and | cad/stl .
cad/drawings/SLH-DWG-001 | and | SLH-DWG-002 : general arrangement of the capstan and the system layout;
SLH-DWG-101 | to | SLH-DWG-110 : making sketches.
docs/04-calcs/01-sizing.md | and | docs/04-calcs/sizing.py | (SLH-CAL-001): loads, forces, strengths and
masses.
bom/bom.csv : parts, specifications and prices.
docs/decisions/0002-design-for-construction.md | (SLH-DDR-002) and | docs/decisions/0003-amish-
requirement-decisions.md | (SLH-DDR-003): the changes in section 2.
cad/src/build_plan_media.py : every picture in this plan.

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
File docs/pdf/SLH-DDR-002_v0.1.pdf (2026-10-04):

S I LT H A U L · D E S I G N D E C I S I O N R E C O R D

# SiltHaul design for construction

### Design Molecule Lab · designmolecule.com

D O C U M E N T CO N T RO L

Document ID | SLH-DDR-002 | Version | 0.1
Status | Draft | Date | 2026-10-03
Author | Amish Chadha | License | CERN-OHL-S-2.0
Project TRL | TRL 3 | Proof of concept
Repository | github.com/BoujeeEnjinia1701/silthaul
Source | docs/decisions/0002-design-for-construction.md @ uncommitted

R EV I S I O N H I STO RY

Version | Date | Author | Change
0.1 | 2026-10-03 | Amish Chadha

Constructability review and changes that make the design buildable, decided under Amish's pre-approval of 2026-10-03

D R A F T · N O T F O R F A B R I C A T I O N

# 0002: Design for construction

Date: 2026-10-03
Status: accepted

## Context

STANDARDS section 18 asks for every part to be makeable by its stated process and to fit and fasten to its neighbours (Amish, 2026-09-30: "fix the design assumptions to match and be physically feasible"). The TRL 2 concept (SLH-PRC-001 v0.2, SLH-DDR-001) was reviewed part by part in cad/src/model.py : how each part is made, how it joins each neighbour, and build123d checks for overlapping parts and for parts that do not touch what holds them. The checks now report no overlaps and no floating parts. Amish pre-approved every recommendation on 2026-10-03: "start with the first 14 repos from the list of 29 projects. I pre-approve the batch runs along with any recommendations you come up with. I also accept any cost overruns or variations from the assumed scope cost." No change alters what SiltHaul does or its pitch; the safety-related changes all take the conservative side.

## Options considered

For each problem the simplest physically sound fix was chosen; the alternatives are noted in Table 1.

## Decision

Table 1. Changes made for construction.

•
•
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

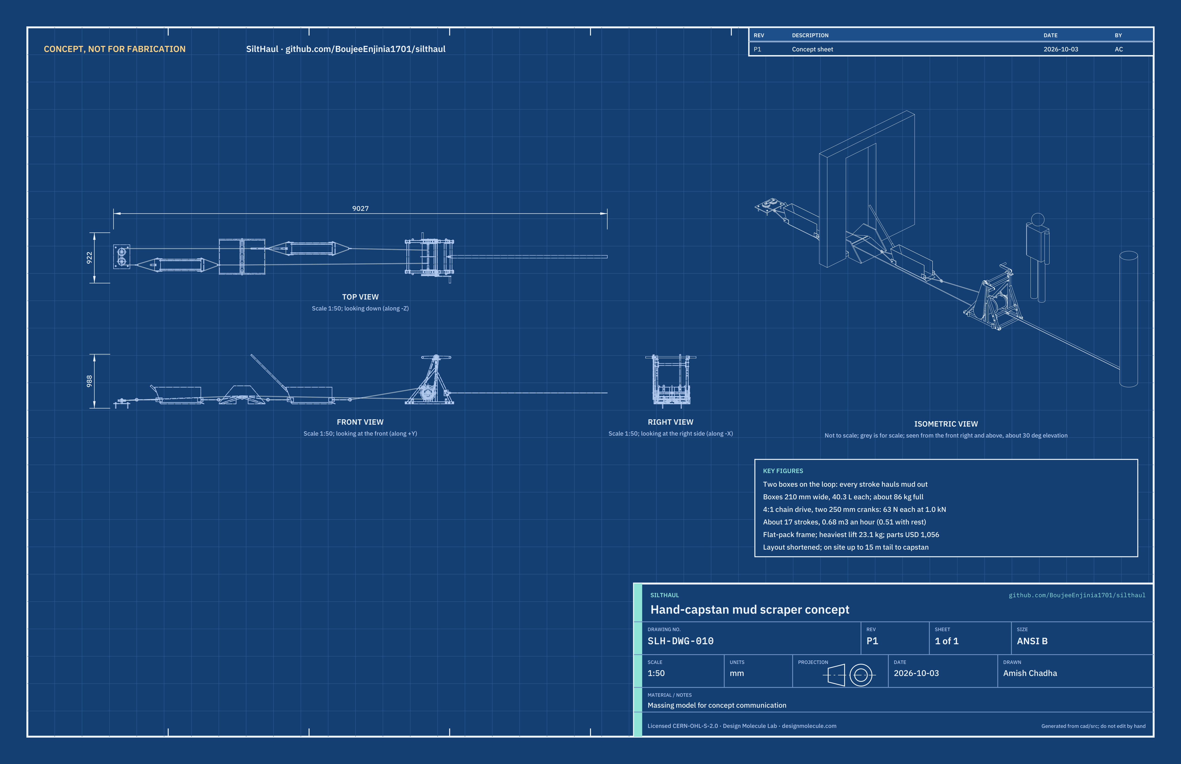
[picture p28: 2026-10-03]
media/concept-blueprint.png

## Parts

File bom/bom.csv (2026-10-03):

item | qty | spec | supplier | unit_cost_usd | make_buy | notes
1 Capstan frame (flat-pack) | 1 | Two welded side frames and four bolted cross members: 40 x 40 x 2 mm steel square tube (S235 or S275) about 8.2 m for rails, posts, pad posts, braces, cross rails and the top tie; 40 x 40 x 3 mm tube 0.52 m for the anchor bar; 8 mm plate for two bearing pads (180 x 50), two top plates (150 x 60) and eight cross member end plates (two 100 x 40 per cross rail, two 40 x 110 for the top tie, two 78 x 104 for the anchor bar); 10 mm plate for the anchor eye; 6 mm plate for two pawl brackets; 12 mm bright bar for two pawl pins; 33.7 x 3.2 mm tube for four stake tubes 80 mm long; 3 mm flat for two guard tabs | Local steel stockholder | 72.00 | make | Indicative material price: USD 62 for the welded frame as before plus USD 10 for the eight end plates (about 0.03 m2 of 8 mm plate, about USD 6) and drilling 24 bolt holes (about USD 4); side frames 9.2 and 9.6 kg, cross members 8.0 kg in all (cad/src/model.py); bolted with line 21 (SLH-DDR-003)
2 Winding drum with ratchet wheels | 1 | Steel tube 219.1 x 3.0 mm, 487 mm long; three flange rings 280 mm OD from 4 mm plate; two 4 mm end discs with six 50 mm lightening holes; 30 mm bright steel shaft (S355 or EN8) 671 mm long; two 24-tooth ratchet wheels 180 mm OD from 6 mm plate (plasma or laser cut); collars from 44 mm tube; two rope clamp blocks with U-bolts | Local steel stockholder and profile cutter | 98.00 | make | Indicative price including profile cutting of the ratchet wheels; 19.0 kg; the big sprocket (line 6) is welded on its hub at the -Y end
3 Drum bearings | 2 | Pillow block ball bearing UCP206, 30 mm bore, cast housing, grease nipple, M14 fixing bolts (in line 21) | Bearing or power transmission distributor | 14.00 | buy | Indicative price; 2.0 kg each; static rating about 11 kN against 3.3 kN at the overload limit (SLH-CAL-001)
4 Crank shaft bearings | 2 | Pillow block ball bearing UCP205, 25 mm bore, cast housing, M12 fixing bolts (in line 21) | Bearing or power transmission distributor | 12.00 | buy | Indicative price
5 Crank shaft and cranks | 1 | 25 mm bright steel shaft (S355 or EN8) 689 mm long with a 4 mm cross hole for the shear pin; two crank arms from 40 x 10 mm flat bar, 250 mm between centres; two 32 mm handle tubes 120 mm long turning on M12 bolts; two shaft collars | Local steel stockholder | 26.00 | make | Indicative price; cranks set 180 degrees apart
6 Sprocket pair ISO 08B-1 | 1 | 12-tooth sprocket with plain bore for a 36 mm hub; 48-tooth plate wheel, pitch diameter 194 mm, bored 30 mm; both 12.7 mm (1/2 in) pitch simplex | Power transmission distributor | 47.00 | buy | Indicative price; 4:1 reduction; small sprocket welded to a 36 mm hub that turns on the crank shaft and is driven through the shear pin
7 Roller chain ISO 08B-1 | 1 | Simplex roller chain 12.7 mm pitch, minimum breaking load 17.8 kN, 1.75 m with one connecting link | Power transmission distributor | 20.00 | buy | Indicative price; 3.5 kN at the overload limit gives a factor of 5.0 (SLH-CAL-001)
8 Pawls | 2 | Pawls profile cut from 8 mm steel plate with a 12 mm pivot hole and a thumb tab; two R-clips and washers; one light spring | Local profile cutter | 8.00 | make | Indicative price; one pawl holds each direction
9 Chain guard | 1 | Closed guard round the chain and both sprockets: 1.5 mm steel sheet sides and a wrapped 1.5 mm band, 20 mm deep inside; shaft holes 4 to 5 mm clear; two M6 screws to the guard tabs | Local fabricator or self made | 20.00 | make | Indicative price; nothing can reach the chain or sprockets with the guard on
10 Shear pins | 20 | 4 mm round bar, S235 mild steel (not hardened), cut 44 mm long; with a split pin each | Local steel stockholder or fastener supplier | 0.30 | buy | Indicative price; releases at about 2.5 kN rope tension (SLH-CAL-001); spare pins on a tag chain at the capstan
11 Ground stakes | 4 | 25 mm round steel bar 600 mm long, pointed, with a 32 mm washer welded on as a head | Local steel stockholder | 6.00 | make | Indicative price; stop the frame skating sideways; not counted as the anchor (SLH-DDR-001)
12 Anchor sling set | 1 | Polyester round sling WLL 2,000 kg, 3 m effective length; two bow shackles WLL 1,000 kg with 19 mm pins; tree protector strap | Lifting gear supplier | 56.00 | buy | Indicative price; the sling pulls level with the drum axis (anchor point no higher than 500 mm)
13 Tail plate with pins and keeper | 1 | 10 mm steel plate 300 x 440 with four 13 mm anchor holes; two 25 mm bright bar pins welded in; two spacer tubes 32 mm OD; 6 mm keeper bar 40 wide with two 25 mm holes; R-clips | Local steel stockholder | 36.00 | make | Indicative price; 11.3 kg with spacers and keeper
14 Tail sheaves | 2 | Steel rope sheave 125 mm pitch diameter for 10 to 12 mm fibre rope, 140 mm OD, 30 mm wide, ball bearing or bronze bush, 25 mm bore, rated at least 1,000 kg | Rigging or hardware supplier | 22.00 | buy | Indicative price
15 Floor anchors | 10 | M12 wedge anchor for sound concrete, 80 mm embedment, zinc plated, with washer and nut (4 in use and 6 spare) | Fastener supplier | 1.80 | buy | Indicative price; needs a 12 mm masonry drill and a sound concrete slab at least 100 mm thick
16 Rope | 62 | 10 mm polyester double braid, minimum breaking strength at least 18 kN, low stretch; cut into a 17 m pull rope (box 1 to the drum), a 17 m return rope (box 2 to the drum) and three tail ropes of 12.5, 9 and 6 m that join the two boxes round the tail sheaves, each with an eye splice at both ends | Rope or chandlery supplier | 1.30 | buy | Indicative price per metre including an allowance for splicing; 7 m more than the single-box kit (USD 9.10) at the same USD 1.30 a metre; eye splices keep about 90 % of the rope strength; the tail rope used is chosen for the room (SLH-BLD-001, step 13)
17 Scraper boxes | 2 | Each: 2 mm steel sheet for floor, sides and sloped back (about 1.2 m2 with waste); 8 x 50 mm flat bar for the cutting lip; 8 x 25 mm flat bar for two skids; 10 mm plate for four bridle lugs; 33.7 x 3.2 mm tube for the tipping bar socket | Local steel stockholder | 80.00 | make | Indicative price each: the first 446 mm box was USD 78 for about 1.0 m2 of sheet; the narrow box uses about 20 % more sheet but a shorter lip, so USD 80; 16.1 kg each; inside 210 x 845 x 280 mm; rated 40.3 L at a 245 mm fill; box 1 on the pull rope, box 2 on the return rope (SLH-DDR-003)
18 Tipping bar | 1 | 26.9 x 2.6 mm steel tube 900 mm long with plastic end caps | Local steel stockholder | 6.00 | make | Indicative price; one bar serves both boxes; loose; drops into a box's socket only at the dump point
19 Doorway ramp | 1 | Two cheeks of 18 mm exterior plywood 840 x 330; two deck trays of 3 mm steel sheet 610 wide with 30 mm side flanges; crest roller of 60.3 x 3.6 mm steel tube 600 long with two nylon end bushes; 20 mm bright bar axle 670 long with R-clips; M8 bolts through cheeks and flanges | Local steel stockholder and timber merchant | 73.00 | make | Indicative price; fits doorways 0.70 m and wider and thresholds up to 110 mm
20 Bridles | 2 | Each set: four bow shackles WLL 1,000 kg with 19 mm pins; 2.4 m of 8 mm grade 30 chain in four legs; two pear rings 56 mm | Lifting gear supplier | 54.00 | buy | Indicative price per set, one set per box; the second set is the same as the first (USD 54); front bridle to the pull or return rope, rear bridle to the tail rope
21 Fasteners | 1 | Four M14 x 50 and four M12 x 45 bolts, nuts and washers (8.8, zinc) for the bearings; eight M10 x 70 and four M12 x 70 bolts (8.8, zinc) with nyloc nuts and washers for the frame cross members; two M6 screws for the guard; twelve M8 x 40 bolts for the ramp; spare R-clips and split pins | Fastener supplier | 33.00 | buy | Indicative price: USD 25 as before plus USD 8 for the twelve frame bolts (about USD 0.65 each with nut and washers)
22 Stop signal and briefing card | 1 | Laminated A5 card with the hand signals and stop rule; two whistles; two high-visibility armbands for the signaller and the crank lead | Print shop and safety supplier | 15.00 | buy | Indicative price; card wording in SLH-PRC-001 and SLH-BLD-001
23 Paint and consumables | 1 | Zinc-rich primer and paint; welding wire or electrodes; grinding and cutting discs; marking paint | Hardware store | 45.00 | buy | Indicative price; USD 5 more than before for priming and painting the second box

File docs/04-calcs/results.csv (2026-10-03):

id | value | target | status
R1 | 0.51 m3/h against 0.90 m3/h for buckets (ratio 0.57); nobody lifts or carries mud | No lifting or carrying of mud; at least 0.5 times the bucket crew | Met on paper
R2 | 63 N each with two at the crank (126 N for one) at 1,000 N | 150 N or less | Met on paper
R3 | 40.3 L a box at a 245 mm fill (46 L to the brim) | About 40 L | Met by design
R4 | Boxes 258 mm over the shackles, pass 42 mm apart; ramp 646 mm; tail plate 440 mm | Pass a 0.7 m opening | Met by design
R5 | 21 turns a half store 12 m of travel; capstan at least 6 m from the door | Up to 15 m tail to capstan | Met by design
R6 | Rope factor 18 working, 5.4 at the 3000 N overload limit; chain 5.0 | At least 5 times the working pull | Met on paper
R7 | Four M12 anchors in the slab, 0.45 of typical recommended loads at the overload limit | Holds on a bare concrete floor, no wall contact | Met on paper (sound slab assumed)
R8 | About 20 min with three people (estimate), at the limit | 20 min or less | Not verifiable at TRL 3
R9 | Heaviest lift 23.1 kg; flat-pack frame, largest piece 890 x 814 x 83 mm; kit 454 L in a 594 L small car boot | Car boot; heaviest part 25 kg or less | Met on paper (rear seats folded)
R10 | 1,055.60 USD | Value-engineering target 2,000 USD | Met on paper, within the target
R11 | Shear pin releases at 2451 N (1961 to 2941 N) | Rope tension limited to 3,000 N | Met on paper
R12 | Two ratchet wheels and pawls on the drum shaft, one for each direction | Holds the load when the cranks are let go | Met by design

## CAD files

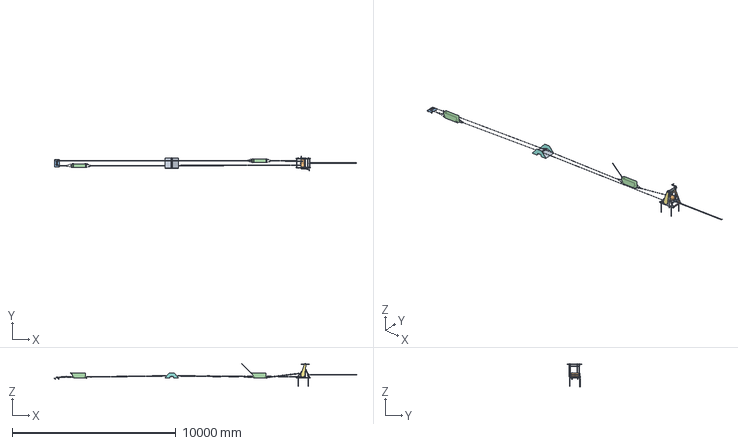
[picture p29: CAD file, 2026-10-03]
cad/step/silthaul-assembly.step
18427.5 x 922.0 x 1427.8 mm

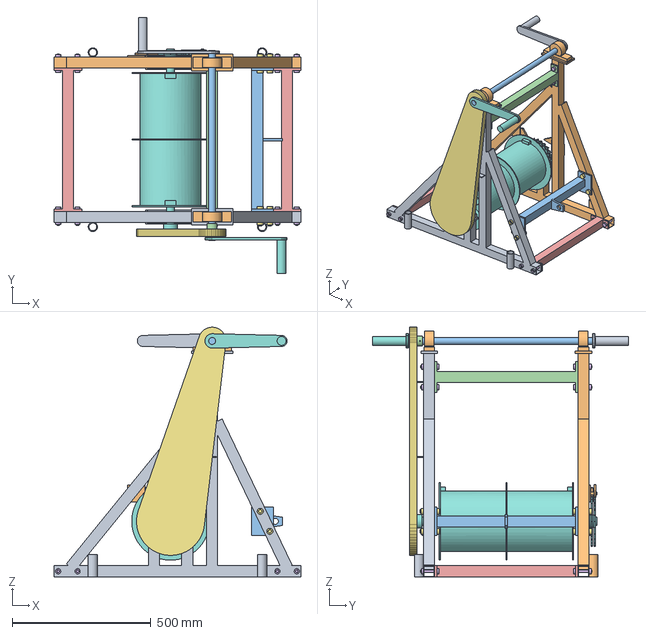
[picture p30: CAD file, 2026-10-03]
cad/step/silthaul-capstan.step
890.0 x 922.0 x 899.5 mm

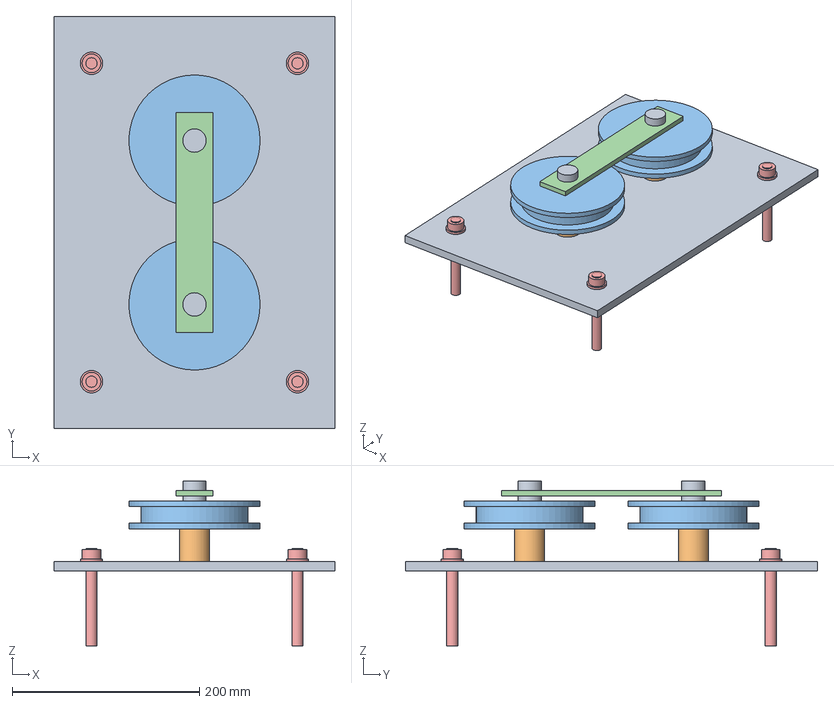
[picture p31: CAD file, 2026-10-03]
cad/step/silthaul-tail.step
300.0 x 440.0 x 176.0 mm

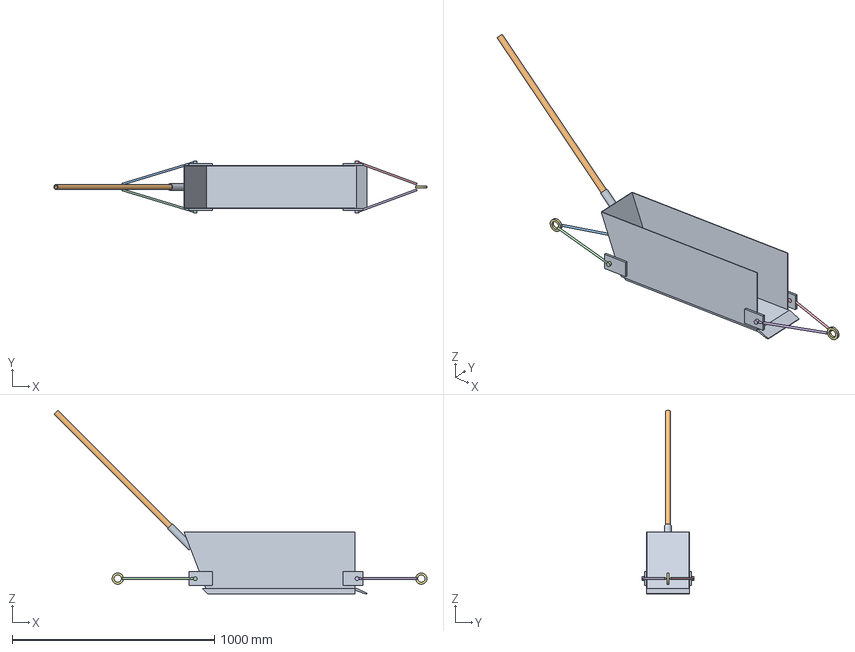
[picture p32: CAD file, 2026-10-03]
cad/step/silthaul-box.step
1844.3 x 258.0 x 907.8 mm

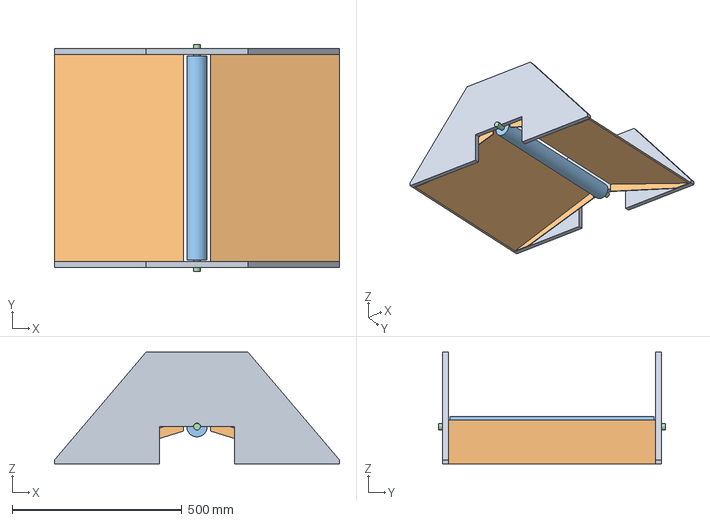
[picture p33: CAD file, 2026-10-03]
cad/step/silthaul-ramp.step
840.0 x 670.0 x 330.0 mm

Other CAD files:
cad/stl/silthaul-box.stl
cad/stl/silthaul-capstan.stl
cad/stl/silthaul-ramp.stl
cad/stl/silthaul-tail.stl

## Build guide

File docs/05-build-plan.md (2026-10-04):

---
doc_id: SLH-BLD-001
title: SiltHaul prototype build plan
project: SiltHaul
doc_type: Build plan
version: "0.3"
status: Draft
date: '2026-10-03'
author: Amish Chadha
license: CERN-OHL-S-2.0
revisions:
- version: "0.1"
  date: '2026-10-03'
  author: Amish Chadha
  change: First build plan; design made constructable (SLH-DDR-002)
- version: "0.2"
  date: '2026-10-03'
  author: Amish Chadha
  change: Second scraper box on the return rope and a bolted flat-pack frame (SLH-DDR-003, Amish's decisions 2A and 7A); steps renumbered
- version: "0.3"
  date: '2026-10-03'
  author: Amish Chadha
  change: "Pack check worded to R9 as restated by Amish (SLH-DDR-004); no design change"
---

# SiltHaul prototype build plan

**Plan, not yet built.** How to build the first proof-of-concept prototype, component by component. Building and testing to it is TRL 4 work. Decisions are kept in the design decisions register ([docs/06-design-decisions.md](06-design-decisions.md)), not here.

## 1. What you are building

Figure 1. Every component, pulled apart and numbered in build order

*Figure 1. Every component pulled apart and numbered in build order: made parts 1 to 17, bought parts 18 to 25. Only one of the two scraper boxes is shown.*

The prototype is a hand-cranked rope haul for flood mud: a capstan that stands outside, a tail sheave block bolted to the floor at the far end of the room, a ramp across the doorway threshold, two steel scraper boxes and three ropes that join them in a loop. One box rides on the pull rope and the other on the return rope, so every turn of the cranks hauls one full box out while the other goes back empty. The capstan frame packs flat: two welded side frames joined on site by four bolted cross members. You weld the side frames, the cross members, the drum, the boxes and the tail plate from stock steel tube, plate, sheet and bar; profile-cut the ratchet wheels and pawls; make the ramp from plywood and folded sheet; and buy the bearings, sprockets, chain, sheaves, anchors, shackles, bolts, sling and rope. The parts cost about USD 1,056 from the bill of materials. The work needs a MIG welder or a small stick welder, a pillar drill and hand tools.

> **Safety:** SiltHaul works with ropes and anchors under tension and a chain drive turned by hand. A failed anchor, shackle or rope can whip; the chain, sprockets, drum and cranks can trap fingers and clothing. The building work involves welding, grinding and drilling concrete. Nobody turns the cranks with the chain guard off, and nothing is loaded before the safety stops in section 6 allow it. Load tests are TRL 4 work.

## 2. What changed to make it buildable

The concept showed what SiltHaul does; some of its parts could not be made or fitted as drawn. Each change keeps what SiltHaul does and is recorded in decision record SLH-DDR-002. The last two rows came later, from Amish's decisions on the requirements, and are recorded in SLH-DDR-003.

*Table 1. Changes from the concept.*

| Component | The concept had | The buildable design has | Why |
| --- | --- | --- | --- |
| Capstan | A friction capstan with the rope loop wrapped round it | A drum in two halves: one winds the pull rope while the other pays out the return rope (Figure 5) | Cannot slip, needs no pretension, the turns cannot walk along the drum |
| Drive | Crank on the drum | 4:1 chain from a crank shaft 850 mm up, two cranks (Figure 13) | 63 N per person at the working pull |
| Overload | None | A 4 mm shear pin in the small sprocket's hub (Figure 9) | Rope tension never passes about 2.5 kN |
| Holding | One ratchet | Two opposite ratchet wheels on the drum shaft, one pawl in front and one behind (Figure 10) | Holds either way, even if the chain fails |
| Frame | 40 x 40 x 3 tube, sling at ground level | 40 x 40 x 2 tube; anchor bar and eye 200 mm up (Figure 11) | Under 25 kg; the sling pulls in line with the ropes |
| Box | Width not set; open front toward the room | 450 mm wide, open front toward the door, sloped back, lugs for bridles (Figure 15) | Box and return rope pass a 0.7 m door together; scoops going out, rides over mud coming back |
| Tail block | One sheave on a floor plate, or a door-frame bar | Two 125 mm sheaves on 25 mm pins, keeper bar, four floor anchors (Figure 17) | Bought sheaves; never bears on a wall |
| Doorway guard | Rope guard on the frame | Ramp with plywood cheeks and a crest roller (Figure 19) | Carries the boxes and the ropes over the threshold |
| Boxes | One 450 mm box; the return rope came back empty | Two boxes 210 mm wide inside and 845 mm long, one on each rope, joined by a tail rope round the tail sheaves (Figure 15) | Mud goes out on every stroke; the boxes pass each other and both fit the ramp in a 0.7 m door |
| Frame | One welded frame, 890 x 663 x 814 mm | Two welded side frames and four bolted cross members (Figures 2, 3 and 4) | Packs flat into a small car boot |

## 3. Making the components

Make and check each component before the step that needs it. Sizes are in millimetres. "Front" is the side of the capstan that faces the house; "+Y side" is the side with the ratchet wheels, "-Y side" the side with the chain. Workshop tolerance is 1 mm unless a step says otherwise. Weld the 2 mm tube with MIG or 2.5 mm electrodes; fillets are 3 mm on tube and 5 mm on plate unless stated. Mark every part with its name in paint marker.

### 3.1 Capstan side frames

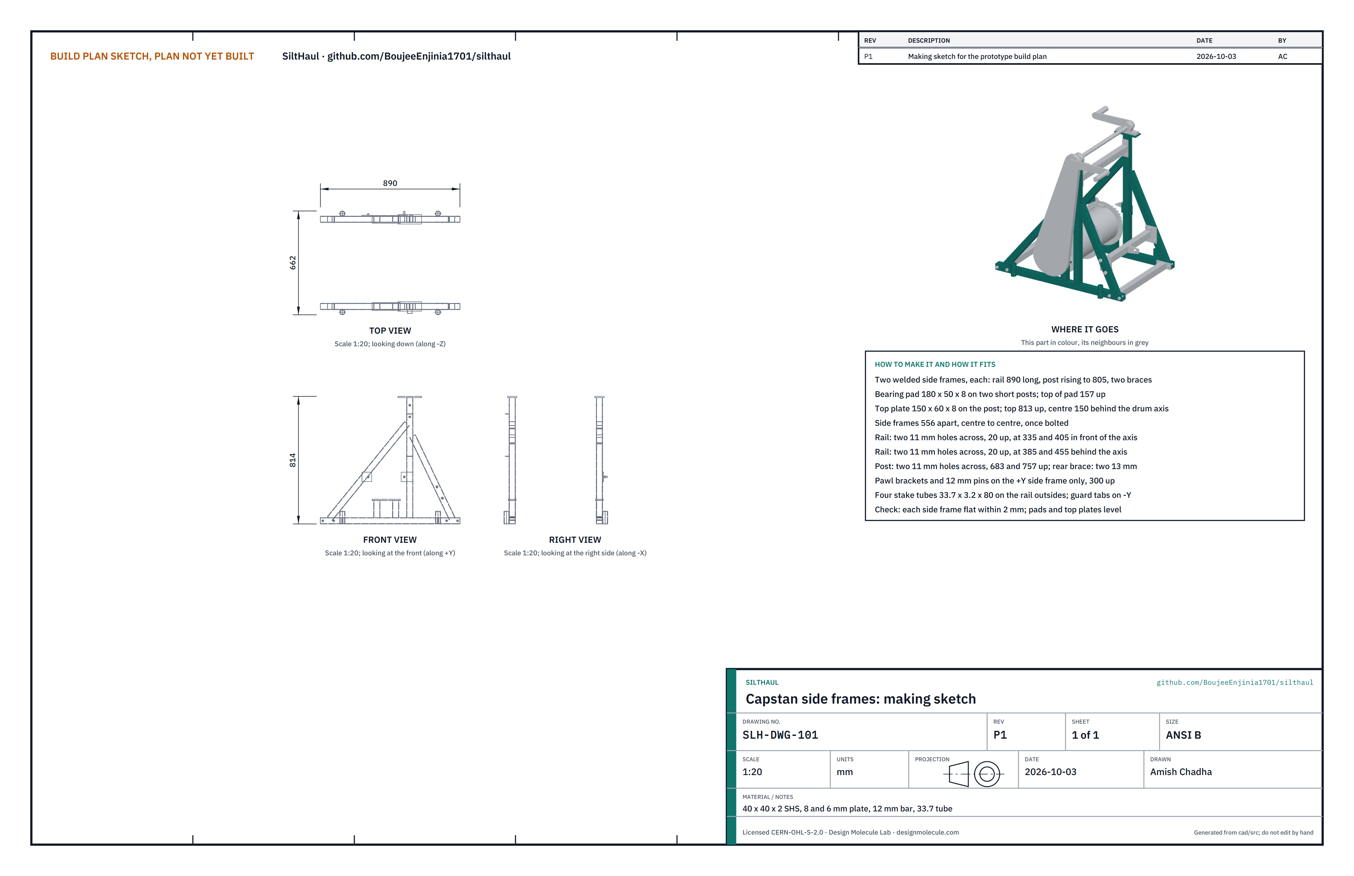
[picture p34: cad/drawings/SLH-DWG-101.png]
Figure 2. Making sketch of the capstan side frames


*Figure 2. Capstan side frames making sketch (SLH-DWG-101).*

**What it is and what it is made from.** The two welded sides of the capstan frame, which carry the drum bearings, the crank bearings and the pawls. They are joined on site by the cross members (section 3.2). 40 x 40 x 2 mm steel square tube; 8 and 6 mm plate; 12 mm bar; 33.7 x 3.2 mm tube.

**How to make it.**

1. For each side frame cut a rail 890 long, a post 765 long and two pad posts 99 long. Cut the braces to fit in step 4.
2. Lay the rail flat. Weld the post upright 150 mm behind the drum axis line and the two pad posts 60 mm each side of the axis line; check square.
3. Weld a bearing pad (180 x 50 x 8) on the two pad posts, its top 157 mm above the floor. Weld a top plate (150 x 60 x 8) on the post, its top 813 mm up.
4. Fit the front brace from 60 mm in from the front end of the rail to the post near 640 mm up, and the rear brace from 50 mm in from the rear end to the post near 560 mm up. Cut the ends to fit and weld.
5. Weld a stake tube (33.7 x 3.2 x 80) upright on the outside of the rail, 280 mm in front of and 330 mm behind the drum axis line.
6. On the +Y side frame only, weld the pawl brackets (6 mm plate): one on the post and one on the front brace, each with a 12 mm pin standing out, 300 mm up, 115 mm behind and 115 mm in front of the drum axis. On the -Y side frame only, weld two guard tabs on the post at 430 and 700 mm up.
7. Drill the bolt holes across each side frame, through both walls: two 11 mm holes in the rail 20 mm up, 335 and 405 mm in front of the axis; two more 385 and 455 mm behind it; two 11 mm holes in the post, 683 and 757 mm up; two 13 mm holes in the rear brace, 40 mm either side of where its centre line passes 200 mm up. Drill these with the cross members clamped in place (section 3.2) so the holes line up.
8. Drill the bearing pad for two M14 bolts at 121 mm centres and the top plate for two M12 bolts at 105 mm centres.

**How it fits the parts next to it.** The cross members bolt to its inside face (Figure 4); the drum bearings bolt on the pads (Figure 6); the crank bearings bolt on the top plates; the pawls hang on the pins (Figure 10).

**Check before moving on.** Each side frame lies flat within 2 mm; the pad and top plate are level; each side frame weighs about 9.5 kg.

### 3.2 Frame cross members

Figure 3. Making sketch of the frame cross members

*Figure 3. Frame cross members making sketch (SLH-DWG-110).*

**What it is and what it is made from.** Four members that hold the two side frames 556 mm apart, centre to centre: the front and rear cross rails on the ground, the top tie between the posts and the anchor bar between the rear braces, which carries the sling eye. 40 x 40 x 2 mm tube; 40 x 40 x 3 mm tube for the anchor bar; 8 mm plate for the end plates; 10 mm plate for the anchor eye.

**How to make it.**

1. Cut three tubes 500 mm long from 40 x 40 x 2 tube and one from 40 x 40 x 3 tube for the anchor bar.
2. Cut eight end plates from 8 mm plate: four 100 x 40 for the cross rails, two 40 x 110 for the top tie and two 78 x 104 for the anchor bar.
3. Weld an end plate square to each end of each tube, so each member is 516 mm over its end plates. On the cross rails the plate sticks out 30 mm each side of the tube; on the top tie it sticks out 35 mm above and below; on the anchor bar it sticks out toward the rear, where the brace is.
4. Weld the anchor eye (10 mm plate, 22 mm hole) to the middle of the anchor bar, pointing back, its hole 200 mm up when the bar is in place.
5. Stand the two side frames on a flat floor, clamp each member in place between them and drill through end plate and side frame together (section 3.1, step 7).
6. Paint each member's ends and the matching place on the side frames the same colour.

**How it fits the parts next to it.**

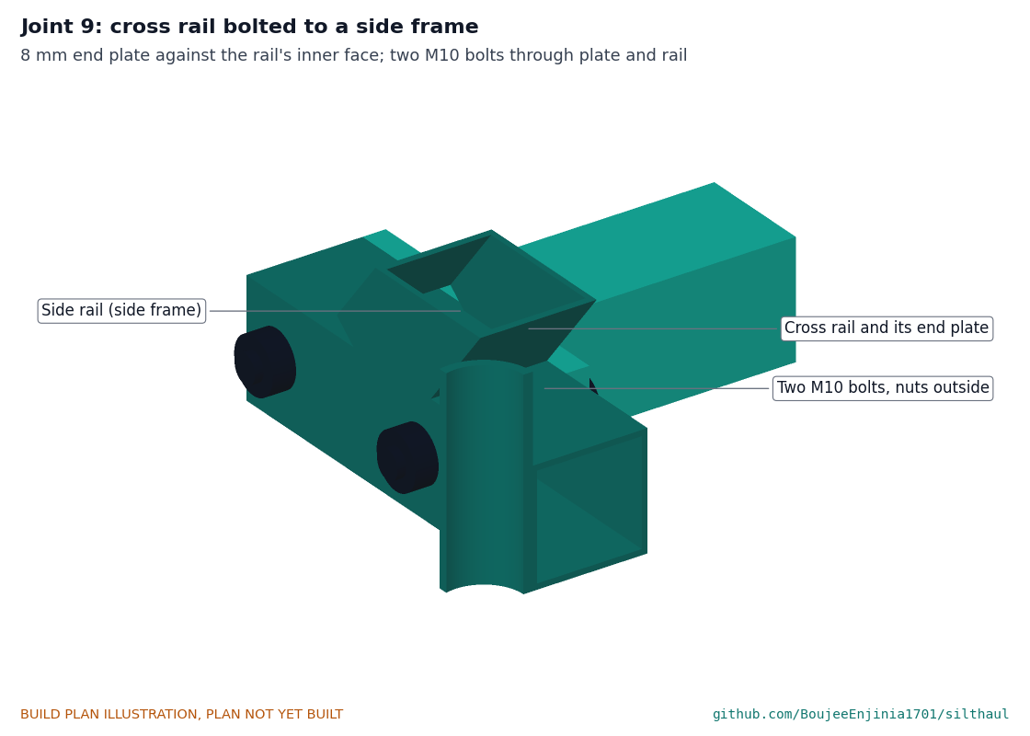
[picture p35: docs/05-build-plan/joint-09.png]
Figure 4. Joint 9: cross rail bolted to a side frame


*Figure 4. Joint 9. The end plate sits flat against the inside face of the side rail; two M10 bolts pass through the plate and both walls of the rail, heads inside and nyloc nuts outside. The top tie bolts the same way to the posts; the anchor bar uses two M12 bolts through each rear brace.*

**Check before moving on.** Bolted up dry, the frame stands without rocking, its base diagonals agree within 3 mm, and both bearing pads are level and in line within 1 mm.

### 3.3 Winding drum

Figure 5. Making sketch of the winding drum

*Figure 5. Winding drum making sketch (SLH-DWG-102).*

**What it is and what it is made from.** The drum that winds the ropes, with the big sprocket and both ratchet wheels on its shaft. 219.1 x 3.0 mm steel tube; 4 mm plate; 30 mm bright steel bar (S355 or EN8); 6 mm plate for the ratchet wheels; the bought 48-tooth sprocket.

**How to make it.**

1. Cut the tube 484 mm long with square ends.
2. Cut two end discs 213 mm across from 4 mm plate with a 30 mm centre hole and six 50 mm lightening holes on a 144 mm circle. Cut three rings 280 mm outside, 219 mm inside, from 4 mm plate.
3. Push the shaft (671 mm long) through both discs; set the discs flush inside the tube ends; check the shaft is central within 0.5 mm; weld the discs to the shaft and the tube in short stitches, turning as you go.
4. Weld a ring at each end and one in the middle; each half between rings is 236 mm, room for 21 turns of rope.
5. At the -Y end, weld the big sprocket to a short hub on the shaft, outboard of where the bearing will sit (Figure 13).
6. At the +Y end, slide on a collar, ratchet wheel 1, a 4 mm spacer and ratchet wheel 2, teeth facing opposite ways as in Figure 10, and weld each to the shaft.
7. Bolt a rope clamp block with a U-bolt to each end ring.

**How it fits the parts next to it.** The shaft runs in the two drum bearings (Figure 6). The pull rope winds from below on the -Y half; the return rope winds from above on the +Y half.

**Check before moving on.** Turned in V-blocks, the rings run true within 2 mm; the sprocket within 1 mm.

### 3.4 Drum bearings (bought)

Figure 6. Joint 1: drum bearing on its pad

*Figure 6. Joint 1. Each UCP206 bearing bolts to its pad with two M14 bolts; its set screws lock the shaft.*

Buy two UCP206 pillow block bearings with 30 mm bores. Nothing to make.

### 3.5 Pawls

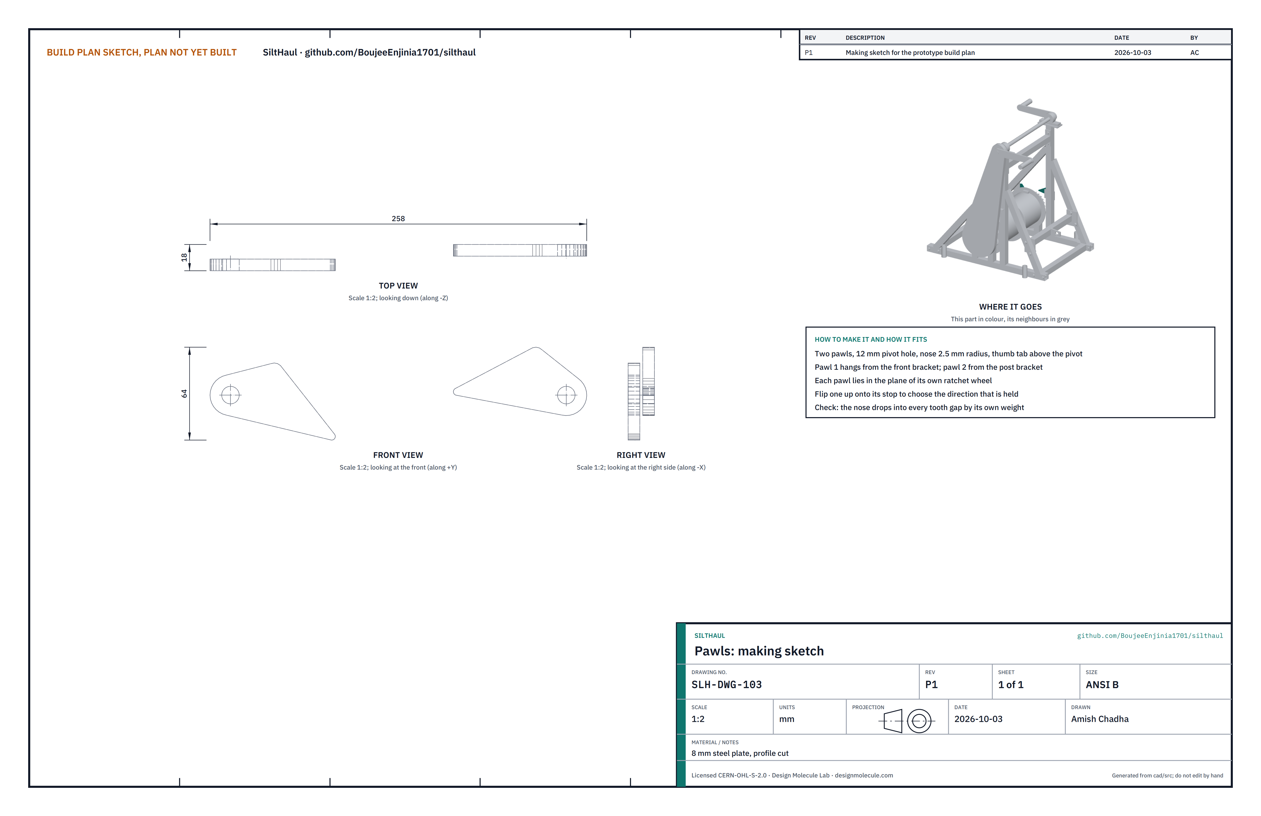
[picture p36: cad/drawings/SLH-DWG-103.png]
Figure 7. Making sketch of the pawls


*Figure 7. Pawls making sketch (SLH-DWG-103).*

**What it is and what it is made from.** Two pawls that stop the drum turning back, one for each direction. 8 mm steel plate, profile cut.

**How to make it.** Cut both from the sketch: a 12 mm pivot hole, a nose with a 2.5 mm radius 85 mm from the drum axis when hanging, and a thumb tab. Deburr; the nose edge stays square.

**How it fits the parts next to it.** Each hangs on its pin in the plane of its own ratchet wheel, held by a washer and an R-clip (Figure 10). To choose the direction held, flip the other pawl up onto its stop.

**Check before moving on.** Each falls into every tooth gap by its own weight as the drum is turned slowly.

### 3.6 Crank shaft, sprocket hub and cranks

Figure 8. Making sketch of the crank shaft, hub and cranks

*Figure 8. Crank shaft, hub and cranks making sketch (SLH-DWG-104).*

**What it is and what it is made from.** The shaft the people turn, and the hub that drives the chain through the shear pin. 25 mm bright steel bar; 36 mm tube for the hub; the bought 12-tooth sprocket; 40 x 10 mm flat bar; 32 mm tube; M12 bolts.

**How to make it.**

1. Cut the shaft 689 mm long.
2. Cut the hub 25 mm long from 36 mm tube bored to slide on the shaft; weld the 12-tooth sprocket to its outer end.
3. Slide the hub on the shaft at the -Y end, clamp, and drill a 4 mm hole through hub and shaft together, square to the shaft.
4. Make two crank arms 250 mm between hole centres; bore one end for the shaft and drill the other for an M12 handle bolt. Pin each arm to the shaft with a 6 mm roll pin, the two arms 180 degrees apart.
5. Fit a 32 mm handle tube, 120 long, on each M12 bolt so it turns freely.

**How it fits the parts next to it.**

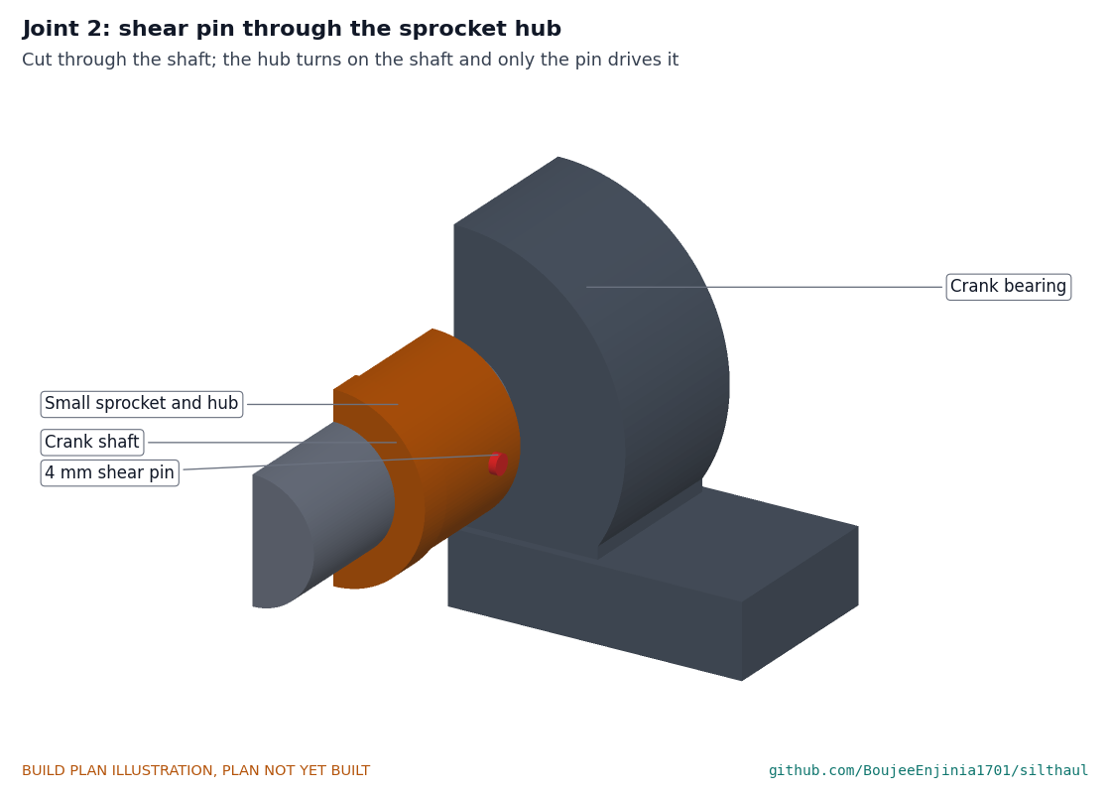
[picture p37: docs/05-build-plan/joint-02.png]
Figure 9. Joint 2: shear pin through the sprocket hub


*Figure 9. Joint 2. The hub turns freely on the shaft; only the 4 mm pin passes the drive. If the rope tension passes about 2.5 kN, the pin shears and the cranks spin free while a pawl holds the drum.*

**Check before moving on.** With the pin out the hub turns freely by hand; with it in, it does not move.

### 3.7 Ratchet wheels and pawls together

Figure 10. Joint 3: ratchet wheels and pawls

*Figure 10. Joint 3. The two ratchet wheels face opposite ways; the pawl in front holds one, the pawl behind holds the other. Here one is down and one is lifted.*

### 3.8 Anchor eye and sling

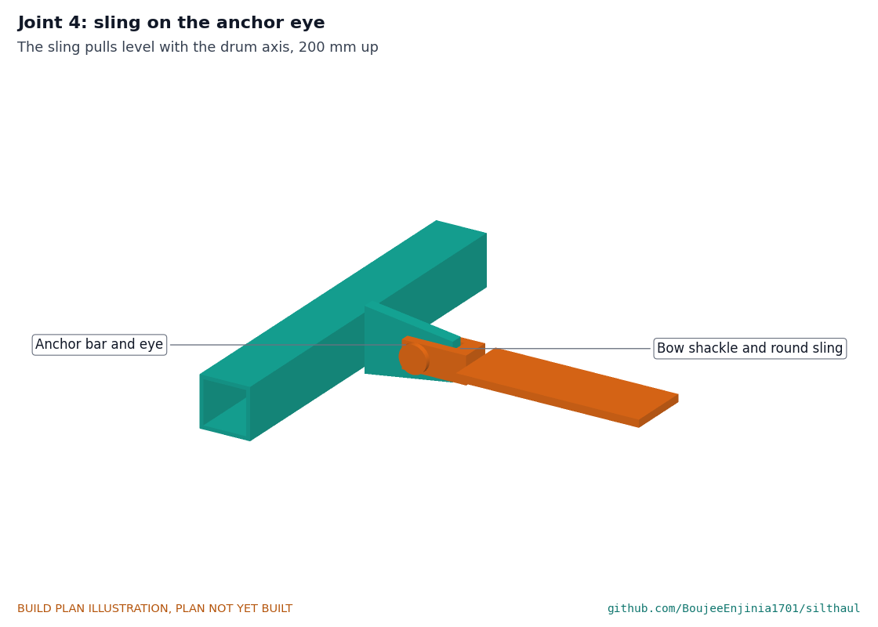
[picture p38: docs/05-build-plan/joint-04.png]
Figure 11. Joint 4: sling on the anchor eye


*Figure 11. Joint 4. The bow shackle's 19 mm pin goes through the 22 mm hole in the eye; the round sling sits in the bow. The pull is 200 mm up, in line with the ropes.*

### 3.9 Chain guard

Figure 12. Making sketch of the chain guard

*Figure 12. Chain guard making sketch (SLH-DWG-105).*

**What it is and what it is made from.** A closed box round the chain and both sprockets. 1.5 mm steel sheet.

**How to make it.**

1. Mark both side sheets from the sketch: the outline round both sprockets with 22 mm clearance.
2. Cut the holes in the inner sheet for both hubs and in the outer sheet for the crank shaft, each 4 to 5 mm clear.
3. Bend a band 20 mm wide round the outline and stitch weld or rivet both sheets to it.
4. Drill for two M6 screws to match the guard tabs.

**How it fits the parts next to it.**

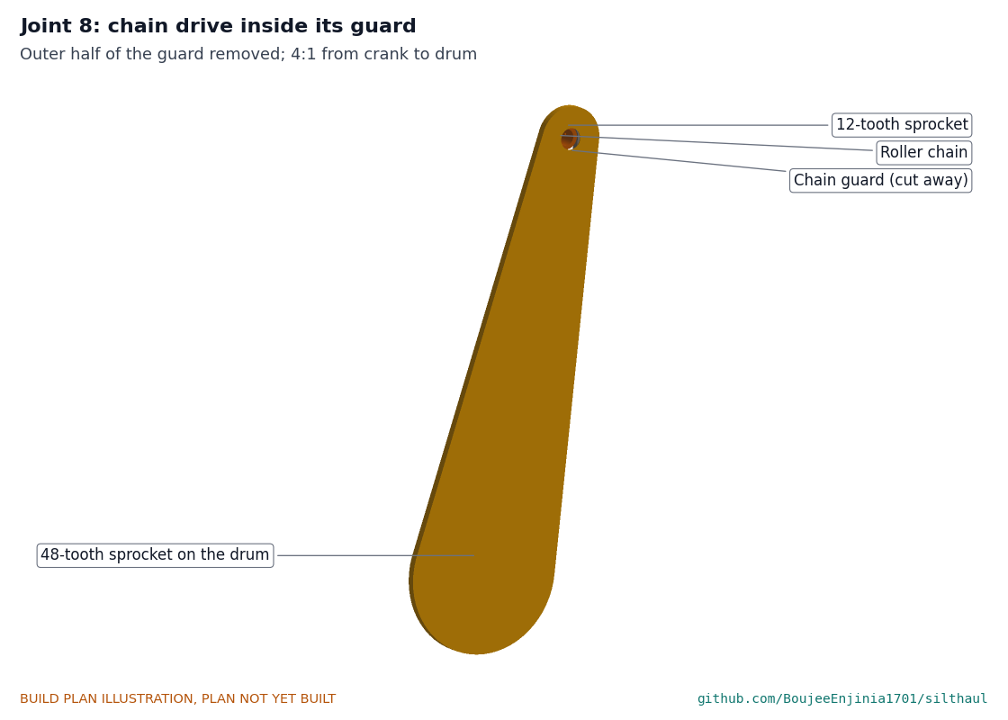
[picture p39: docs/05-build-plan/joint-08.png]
Figure 13. Joint 8: chain drive inside its guard


*Figure 13. Joint 8, outer half of the guard removed. The chain runs 4:1 from the small sprocket on the crank shaft to the big sprocket on the drum.*

**Check before moving on.** With the guard on, a finger cannot reach the chain or sprockets through any gap.

### 3.10 Ground stakes (make 4)

Figure 14. Making sketch of a ground stake

*Figure 14. Ground stake making sketch (SLH-DWG-106).*

**What it is and what it is made from.** Pins that stop the capstan skating sideways. 25 mm round bar 600 long; a 32 mm washer.

**How to make it.** Grind one end to a point; weld the washer on the other end as a head.

**How it fits the parts next to it.** Each is driven through a stake tube until its head rests on the tube. The stakes are not the anchor; the sling is.

**Check before moving on.** Straight within 3 mm.

### 3.11 Scraper boxes (make 2) and tipping bar

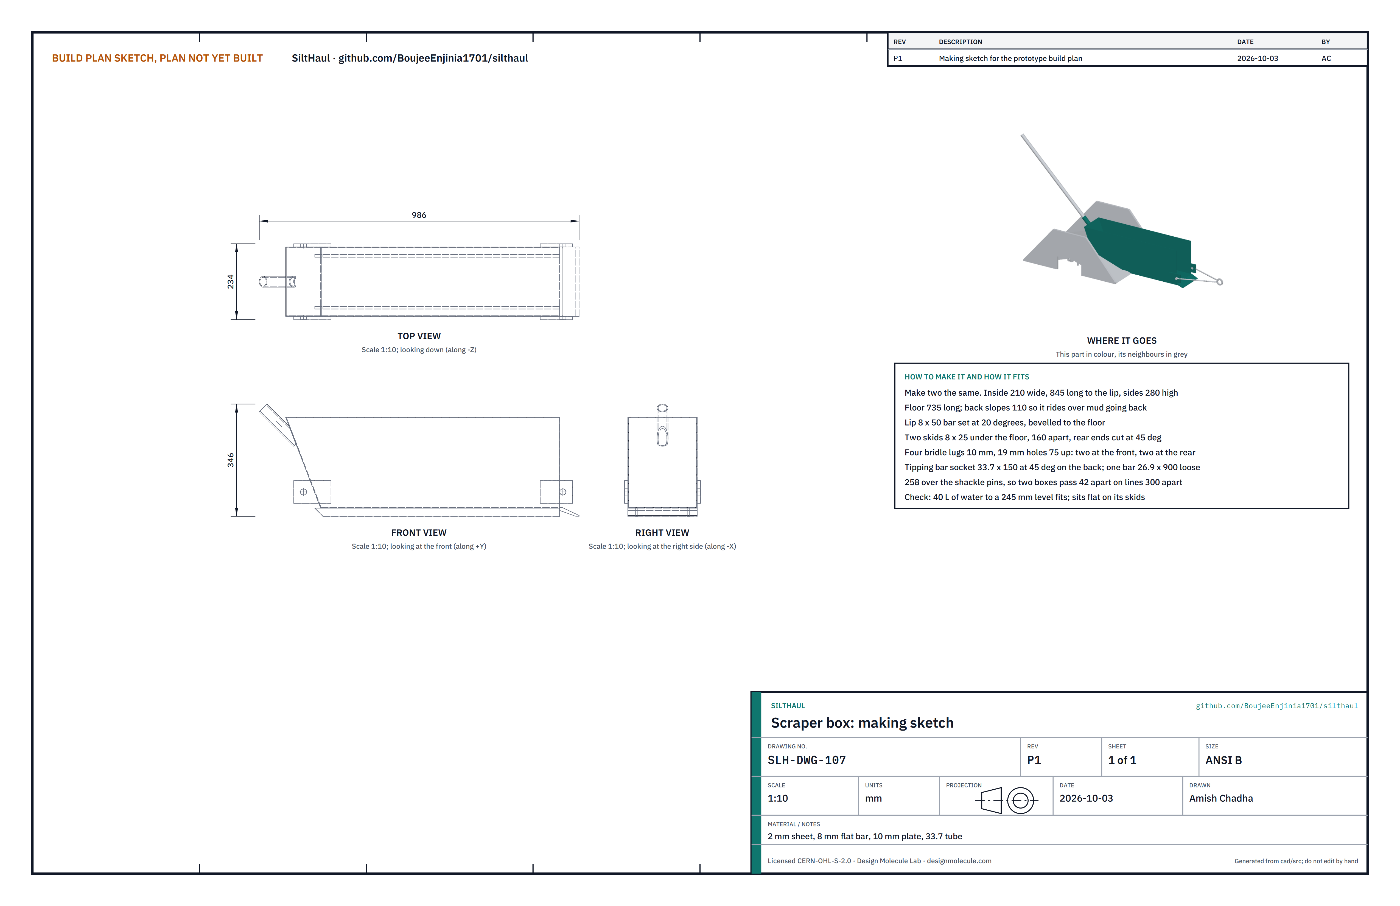
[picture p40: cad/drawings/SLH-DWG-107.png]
Figure 15. Making sketch of a scraper box


*Figure 15. Scraper box making sketch (SLH-DWG-107). Make two the same.*

**What it is and what it is made from.** The boxes that carry the mud, one on each rope. Each: 2 mm steel sheet; 8 x 50 and 8 x 25 mm flat bar; 10 mm plate; 33.7 x 3.2 mm tube. One 26.9 x 2.6 mm tube 900 long for the tipping bar, shared by both boxes.

**How to make it.** For each box:

1. Cut the floor 735 x 210, the sloped back 301 x 210 and two sides with a sloping rear edge (845 long at the top, 735 at the floor line plus the 110 mm slope, 280 high).
2. Tack the floor, back and sides together on a flat table; the back leans out 110 mm over its 280 mm height; weld inside and out.
3. Weld the two skids (8 x 25 bar) under the floor, 160 mm apart, their rear ends cut at 45 degrees.
4. Weld the lip (8 x 50 bar, the full width) to the front of the floor at about 20 degrees down, and grind its front edge to a bevel that touches the ground.
5. Weld two bridle lugs (10 mm plate, 19 mm hole 75 mm up) on the outside of each side: at the front, the hole 10 mm ahead of the lip line; at the rear, the hole 55 mm from the back's top edge, behind the sloped back.
6. Weld the socket tube (150 long) to the middle of the back, pointing up and back at 45 degrees, meeting the back 65 mm below its top edge.
7. Cap both ends of the tipping bar.

The box is narrow so that the two boxes, on rope lines 300 mm apart, pass each other 42 mm apart in the room and both run over the ramp inside its cheeks.

**How it fits the parts next to it.**

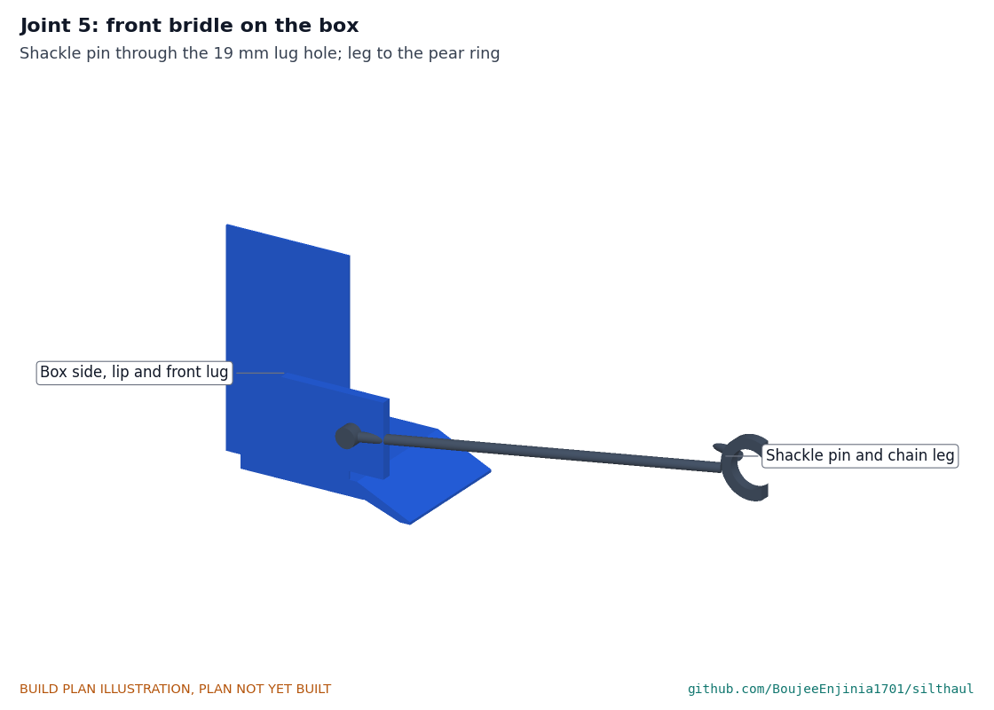
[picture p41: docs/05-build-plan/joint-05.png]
Figure 16. Joint 5: front bridle on the box


*Figure 16. Joint 5. A bow shackle's pin goes through each front lug; a leg of 8 mm chain runs from each shackle to a pear ring 300 mm ahead. The rear bridle is the same, behind the box.*

**Check before moving on.** 40 L of water poured in comes to about 245 mm deep (cover the open front with a board); each box sits flat on its skids and measures 258 mm over its shackle pins.

### 3.12 Tail plate, pins and keeper

Figure 17. Making sketch of the tail plate, pins and keeper

*Figure 17. Tail plate, pins and keeper making sketch (SLH-DWG-108).*

**What it is and what it is made from.** The block at the far end of the room that turns the rope back. 10 mm plate 300 x 440; 25 mm bright steel bar (S355); 32 mm tube; 6 x 40 mm flat bar.

**How to make it.**

1. Cut the plate; drill four 13 mm anchor holes at the corners of a 220 x 340 rectangle.
2. Drill two 25 mm holes on the plate's centre line across, 175 mm apart; push in the pins (85 mm long), check square, and weld above and below.
3. Cut two spacers 35 mm long from 32 mm tube.
4. Cut the keeper bar 255 long, drill two 25 mm holes 175 apart, and drill each pin top for an R-clip.

**How it fits the parts next to it.**

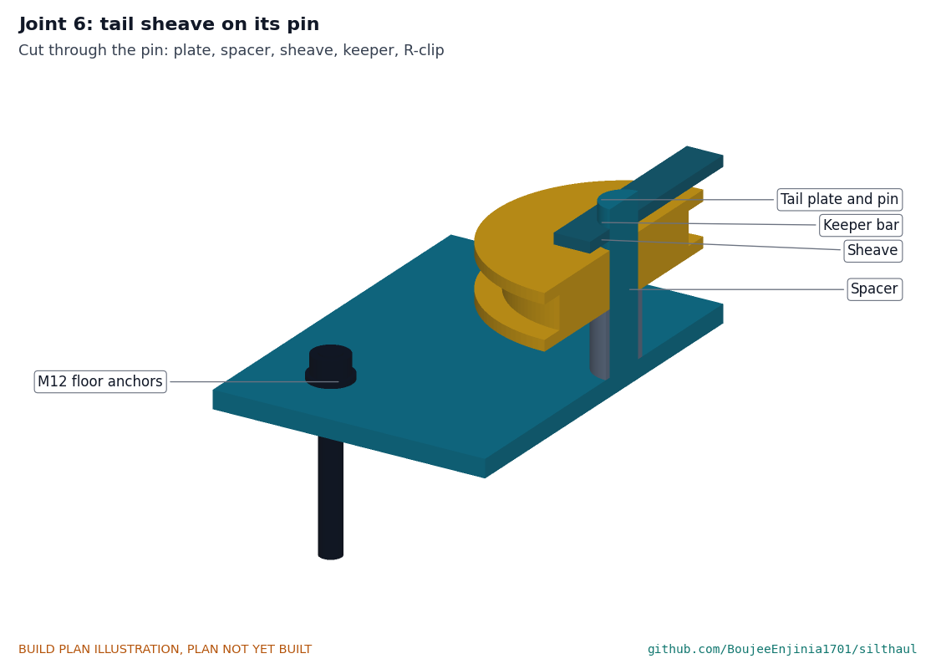
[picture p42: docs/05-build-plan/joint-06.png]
Figure 18. Joint 6: tail sheave on its pin


*Figure 18. Joint 6, cut through a pin. Plate, spacer, sheave, keeper bar and R-clip stack on the pin; the rope groove sits 60 mm above the floor. M12 anchors pass through the plate into the slab.*

**Check before moving on.** Pins square within 1 degree; the keeper drops over both pins; each sheave turns freely.

### 3.13 Doorway ramp

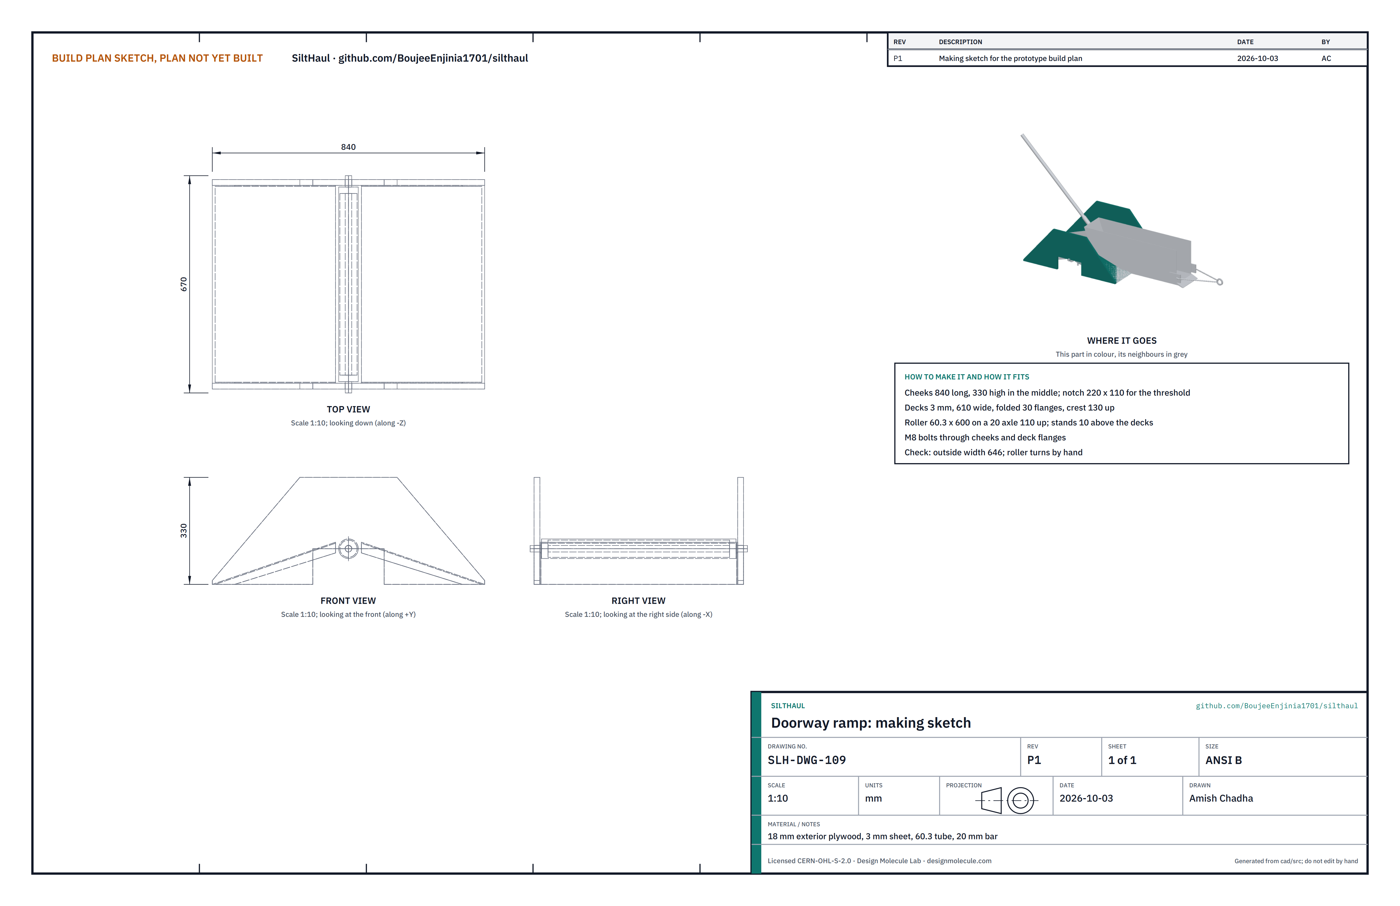
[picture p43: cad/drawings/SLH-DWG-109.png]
Figure 19. Making sketch of the doorway ramp


*Figure 19. Doorway ramp making sketch (SLH-DWG-109).*

**What it is and what it is made from.** A ramp that carries both boxes and the ropes over the threshold and keeps the ropes off the door frame. 18 mm exterior plywood; 3 mm steel sheet; 60.3 x 3.6 mm tube; 20 mm bar; two nylon bushes; M8 bolts.

**How to make it.**

1. Cut two cheeks from plywood: 840 long, rising to 330 high over the middle 300, with a notch 220 wide and 110 high underneath for the threshold. Drill a 21 mm hole 110 mm up at the middle.
2. Cut and fold two deck trays from 3 mm sheet: 610 wide, each running from the floor to 130 mm up over 380 mm, with 30 mm flanges turned down each side.
3. Cut the roller 600 long; press a nylon bush into each end.
4. Bolt the flanges through the cheeks with M8 bolts; the deck tops meet the floor in a thin edge and stop 40 mm short of the middle.
5. Push the axle through one cheek, the roller and the other cheek; R-clip both ends.

**How it fits the parts next to it.**

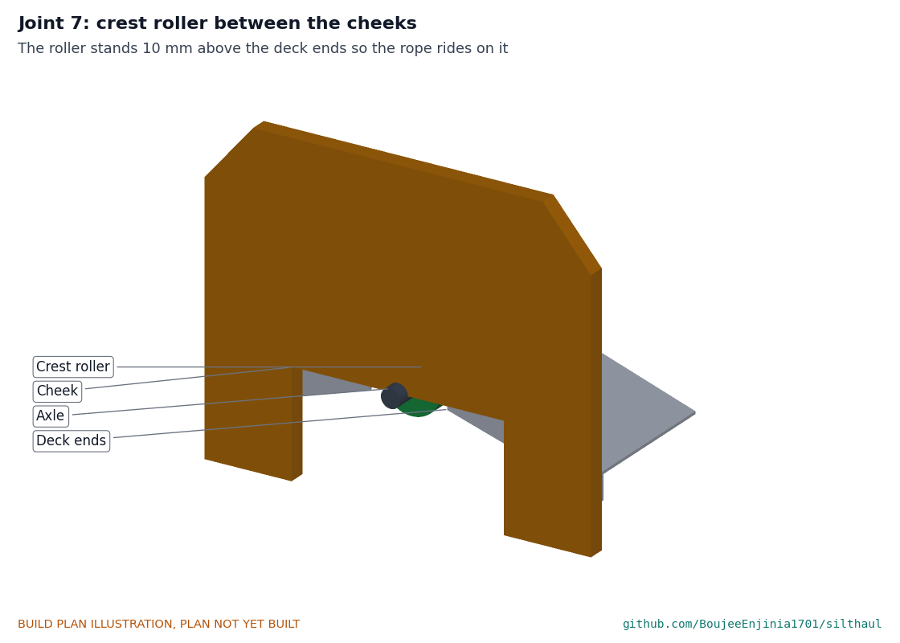
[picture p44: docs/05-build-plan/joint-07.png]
Figure 20. Joint 7: crest roller between the cheeks


*Figure 20. Joint 7. The roller stands 10 mm above the deck ends, so the ropes and the boxes ride over it rather than over the edges.*

**Check before moving on.** 646 mm outside; the roller turns by hand; the ramp sits flat over a 110 mm threshold; set in the doorway, its middle lies midway between the two rope lines, so each box runs 26 mm inside a cheek.

### 3.14 Bought components

Buy to specification, not brand. Line numbers are those of the bill of materials.

- **Bearings (lines 3 and 4).** Two UCP206 (30 mm) and two UCP205 (25 mm) pillow block ball bearings.
- **Sprockets and chain (lines 6 and 7).** ISO 08B-1 (12.7 mm pitch): a 12-tooth sprocket bored to suit the hub and a 48-tooth plate wheel bored 30 mm; 1.75 m of chain with breaking load at least 17.8 kN and one connecting link.
- **Shear pins (line 10).** 4 mm S235 mild steel bar cut 44 mm long, with split pins; never hardened steel.
- **Sling and shackles (lines 12 and 20).** A 3 m polyester round sling, WLL 2,000 kg; ten bow shackles WLL 1,000 kg with 19 mm pins (two for the sling, four for each box); a tree protector strap; 4.8 m of 8 mm grade 30 chain; four 56 mm pear rings.
- **Tail sheaves (line 14).** Two steel sheaves, 125 mm pitch diameter for 10 to 12 mm fibre rope, 25 mm bore, rated at least 1,000 kg.
- **Floor anchors (line 15).** M12 wedge anchors for sound concrete, 80 mm embedment; ten, so six are spare.
- **Rope (line 16).** 62 m of 10 mm polyester double braid, minimum breaking strength at least 18 kN, cut into a 17 m pull rope, a 17 m return rope and three tail ropes of 12.5, 9 and 6 m, each with an eye splice at both ends.
- **Fasteners and consumables (lines 21 and 23).** Four M14 x 50 and four M12 x 45 bolts for the bearings; eight M10 x 70 and four M12 x 70 bolts with nyloc nuts and washers for the frame; M6 screws, M8 bolts for the ramp, R-clips; primer, paint, welding wire and discs.
- **Stop signal and briefing card (line 22).** A laminated card with the hand signals and stop rule, two whistles and two armbands.

## 4. Putting it together

In each picture the parts already fitted are grey and the part being fitted is in colour, with an arrow showing the way it goes in. Steps 1 to 9 are done in the workshop for a trial assembly and repeated on site; steps 10 to 13 are done on site only. Two people throughout.

### Step 1: bolt the frame together

Step 1

Stand the two side frames upright, ratchet side (+Y) on the right when you look from the front. Fit the front and rear cross rails, the top tie and the anchor bar between them, matching the paint marks. Two bolts at each end, heads inside, washers and nyloc nuts outside: M10 for the rails and the tie, M12 for the anchor bar. Tighten firmly; check the base diagonals agree within 3 mm.

### Step 2: drum bearings onto the drum shaft

Step 2

Slide a UCP206 bearing onto each end of the drum shaft, grease nipple up, set screws loose. The drum lifts with its bearings: 23 kg.

### Step 3: lower the drum onto the pads

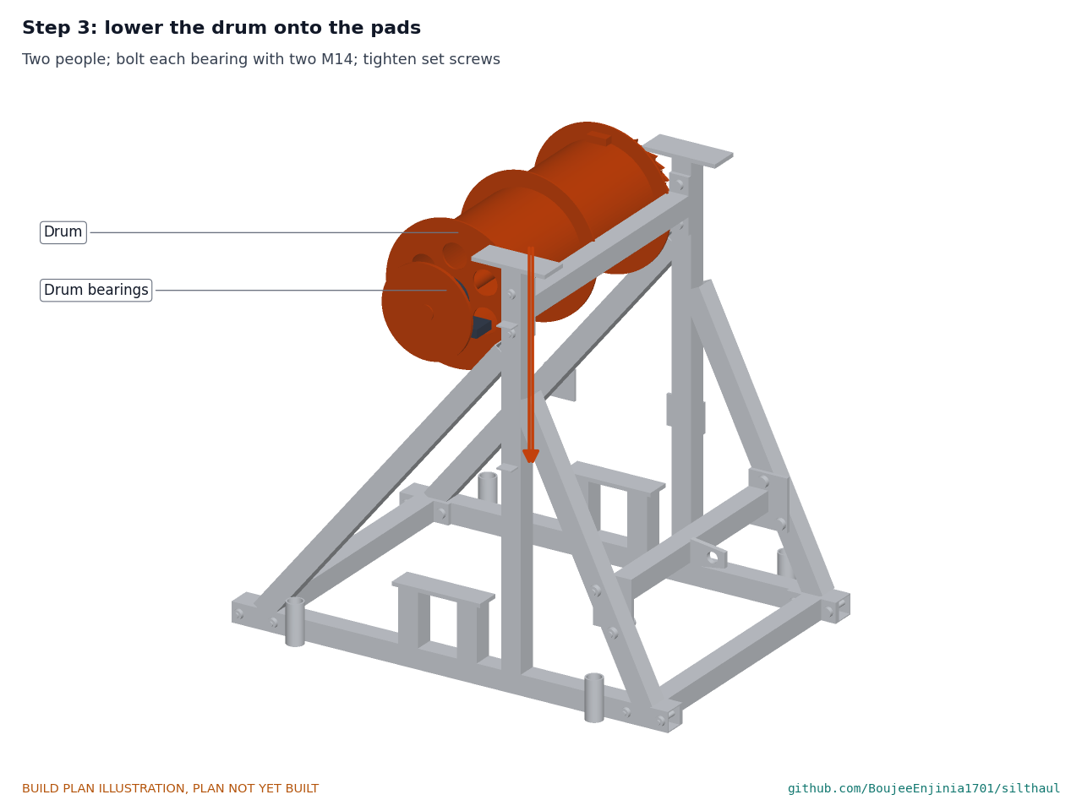
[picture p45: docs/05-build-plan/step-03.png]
Step 3


Two people lower the drum and bearings onto the pads, sprocket to the -Y side. Bolt each bearing with two M14 bolts; centre the drum between the frame sides; tighten the set screws.

### Step 4: crank shaft, hub and bearings onto the top plates

Step 4

Slide the crank bearings onto the crank shaft, with the sprocket hub on the -Y end. Bolt the bearings to the top plates with M12 bolts, the small sprocket in line with the big one within 1 mm.

### Step 5: fit the chain

Step 5

Lay the chain over both sprockets and join it with the connecting link, the clip's closed end leading in the haul direction. The chain should lift about 10 mm at mid-span by hand.

### Step 6: fit the shear pin

Step 6

Push a 4 mm shear pin through the hub and shaft and fit its split pin. Hang the spares on the tag chain at the capstan.

### Step 7: chain guard on

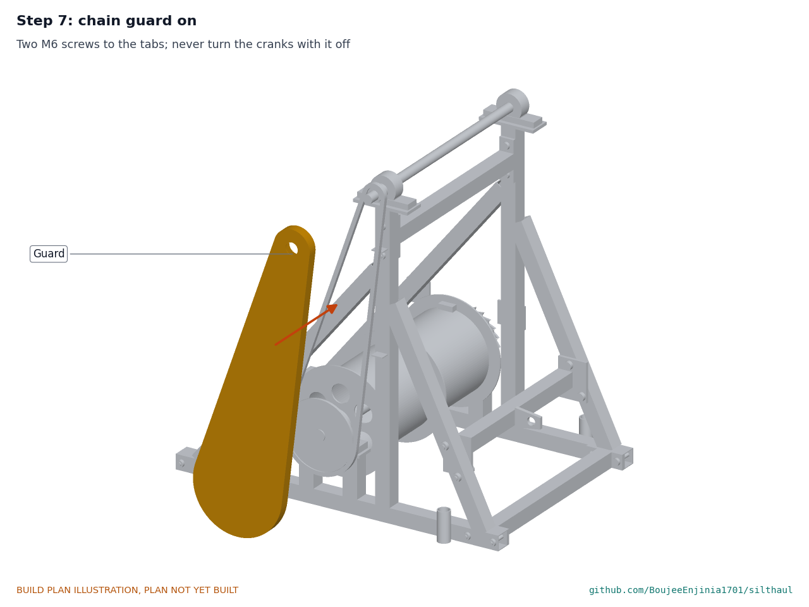
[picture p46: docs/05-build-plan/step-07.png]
Step 7


Fit the guard over the chain and fix it with two M6 screws to the tabs. From now on, the cranks are never turned with it off.

### Step 8: cranks on

Step 8

Fit a crank arm to each end of the crank shaft, 180 degrees apart, and roll-pin each.

### Step 9: pawls on their pins

Step 9

Hang each pawl on its pin with a washer and an R-clip. Flip one up onto its stop.

### Step 10: set the capstan, stakes and sling

Step 10

For carrying, the capstan comes apart into the two side frames, the four cross members, the drum with its bearings and the crank shaft with its cranks; the frame pieces lie flat. On site, repeat steps 1 to 9. Set the capstan on firm level ground at least 6 m beyond the door, its drum square to the line from the tail block through the door. Drive the four stakes. Wrap the sling round a sound tree, low on the trunk with the protector, or a parked vehicle's recovery point; shackle it to the eye so it runs level or rises 10 degrees at most.

### Step 11: anchor the tail block

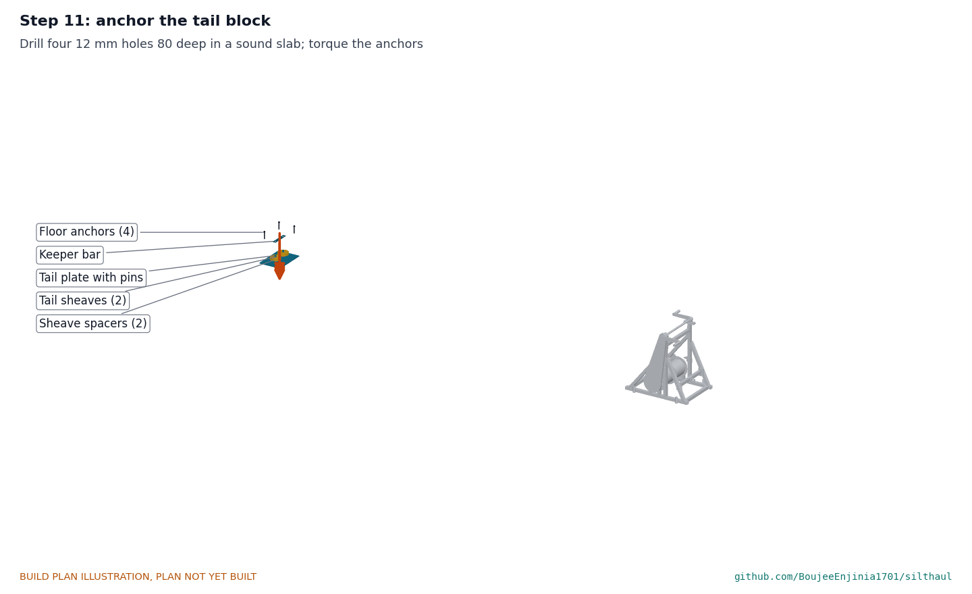
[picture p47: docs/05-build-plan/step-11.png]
Step 11


At the far end of the room, on the line through the door, check the slab (section 6). Drill four 12 mm holes 80 mm deep through the plate holes, clean them, fit the M12 anchors and tighten to the maker's torque. Stack spacers, sheaves and keeper on the pins; R-clip.

### Step 12: ramp across the threshold

Step 12

Stand the ramp in the doorway with its cheeks straddling the threshold, the roller square to the rope line and the ramp's middle midway between the two rope lines.

### Step 13: reeve the ropes and shackle both boxes

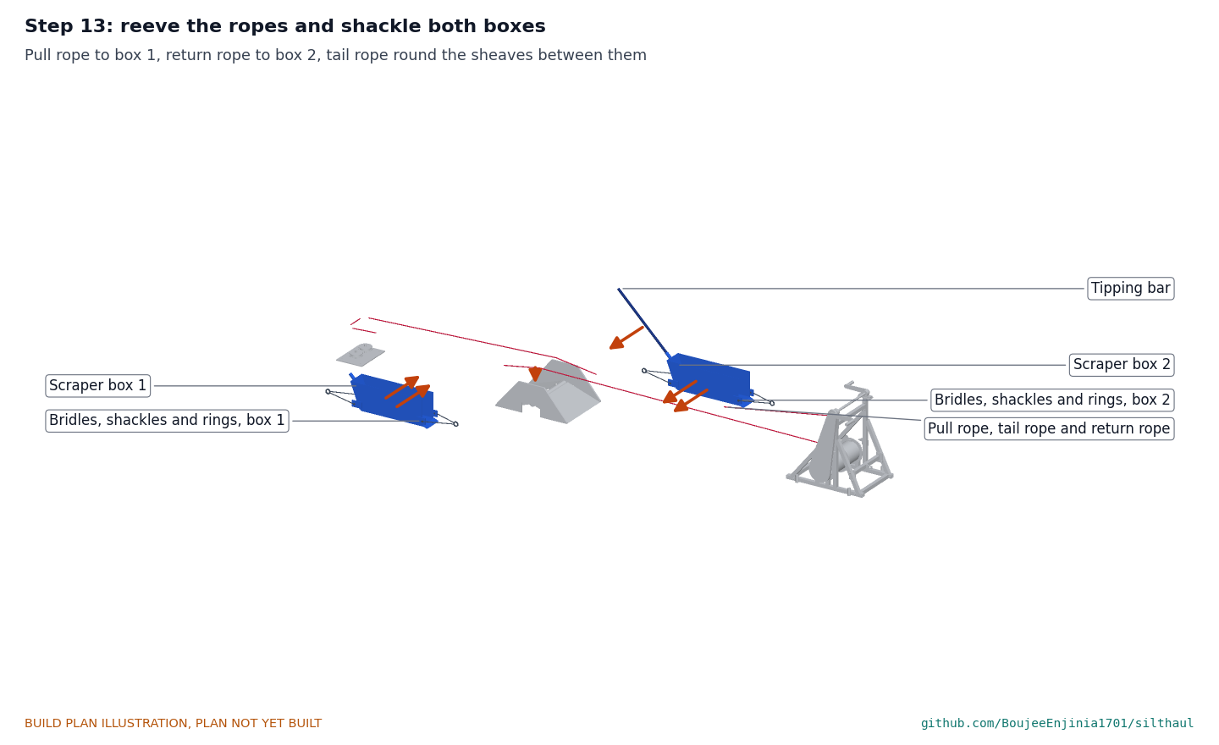
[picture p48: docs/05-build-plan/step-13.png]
Step 13


Choose the tail rope for the room: the longest of the three (12.5, 9 or 6 m) that is at least 1.5 m longer than the room and at least 2.3 m shorter than the distance from the tail block to the capstan. Set box 1 at the far end of the room on the line through the -Y half of the drum, and box 2 outside, between the ramp and the capstan, on the line through the +Y half, both with their open fronts toward the door. Clamp the pull rope's end to the drum's -Y half, wind on three turns from below, run it over the ramp roller and shackle it to box 1's front bridle ring. Clamp the return rope's end to the +Y half, wind on three turns plus the turns for box 2's distance from the capstan from above, and shackle it to box 2's front bridle ring. Shackle the tail rope to box 1's rear ring, take it round both tail sheaves, back over the ramp roller beside box 1's line, and shackle it to box 2's rear ring. Take up the slack with the cranks until all the ropes are just off the floor.

## 5. First checks

These are listed here and recorded in a TRL 4 test report, not in this plan.

*Table 2. First checks.*

| Check | Requirement | How | Pass when |
| --- | --- | --- | --- |
| Fit through the door | R4 | Carry the boxes, tail block and ramp through a 0.7 m opening; haul both boxes over the ramp and past each other in the room | Nothing touches the door frame; the boxes pass without touching |
| Holding | R12 | At working pull, let go of the cranks in each direction | The drum stops within one tooth; cranks do not kick back past a quarter turn |
| Shear pin release | R11 | Pull the box against a fixed stop through a load cell, cranking slowly | The pin shears between 1,960 and 2,940 N; a pawl holds the drum |
| Proof load of anchors | R6, R7 | CalRig or a load cell, held 1 min: tail block to 9.0 kN (both legs at 1.5 times 3,000 N), capstan sling and frame to 4.9 kN | No movement over 2 mm, no damage |
| Crank force | R2 | Spring balance on a handle with a full box going out and the empty one coming back | 150 N or less per person with two cranking |
| Box capacity | R3 | Fill each box with 40 L of water, front boarded | Level about 245 mm |
| Haul trial | R1, R5 | Full length with both boxes, timed against a bucket crew of the same four people | SiltHaul moves at least half as much; nobody lifts or carries mud |
| Setup | R8 | Three people, timed | 20 min or less |
| Mass and packing | R9 | Weigh each lift; take the frame apart and pack the whole kit into a small hatchback | Each 25 kg or less; the kit fits a small hatchback with the rear seats folded (R9 as restated) |

## 6. Safety stops

Work stops at each of these points until what is listed is true.

1. **Before any rope is put under load.** The building has been checked for structural damage and the electricity is off. The chain guard is on. A pawl is down. Everyone has been briefed with the card: one signaller, whistle and hand signals; one blast stops the cranks.
2. **Before fitting the tail block.** The slab has been drilled and is sound concrete at least 100 mm thick, with no hollow sound under tiles and no cracks within 150 mm of a hole. If not, SiltHaul is not used in that room.
3. **Before the first haul on a site.** Every anchor has been proof-loaded for 1 min at 1.5 times its load at the 3,000 N limit: the tail block to 9.0 kN and the capstan sling and frame to 4.9 kN with nobody in the rope lines. The rope, splices, shackles and sling have been inspected that day.
4. **Before each haul.** Nobody is inside the loop, in the line of a rope, beside a sheave or within 2 m of the ramp. Loaders stand to the side away from the other box's line and never between the two boxes: they pass each other 42 mm apart.
5. **Before dumping and filling.** The cranks are stopped and a pawl is holding before the crank crew leave the cranks to dump one box and the loaders start filling the other. Two people lift the tipping bar; nobody stands in front of the lip.
6. **After a shear pin breaks.** Stop, find the jam with the rope slack, clear it, then fit a new pin of the same 4 mm S235 bar. Never a bolt, a nail or a harder pin.
7. **At the end of each day.** Inspect the rope for cuts and glazing, the splices, the shackles, the pawls and the anchors; replace anything damaged.

## 7. Tools, skills and workspace

- MIG welder (or a small stick welder with 2.5 mm electrodes) and a person who can weld 2 mm tube without burning through; welding screen, gloves and mask.
- Angle grinder with cutting and grinding discs; metal saw; pillar drill with bits to 25 mm; hammer drill with a 12 mm masonry bit for site.
- Jigsaw for the plywood; bending brake or a vice and hammer for the 1.5 and 3 mm sheet.
- Spanners or sockets for M10 to M14, torque wrench, R-clip pliers, splicing fid if the eye splices are made in-house.
- A flat floor or welding table about 1.0 x 1.0 m for the side frames; two people for the drum.
- Rope work: eye splices in double braid made by a rigger or a trained person.

## 8. Where the numbers come from

- `cad/src/model.py`: the parametric model, its constructability checks and the STEP and STL files in `cad/step` and `cad/stl`.
- `cad/drawings/SLH-DWG-001` and `SLH-DWG-002`: general arrangement of the capstan and the system layout; `SLH-DWG-101` to `SLH-DWG-110`: making sketches.
- `docs/04-calcs/01-sizing.md` and `docs/04-calcs/sizing.py` (SLH-CAL-001): loads, forces, strengths and masses.
- `bom/bom.csv`: parts, specifications and prices.
- `docs/decisions/0002-design-for-construction.md` (SLH-DDR-002) and `docs/decisions/0003-amish-requirement-decisions.md` (SLH-DDR-003): the changes in section 2.
- `cad/src/build_plan_media.py`: every picture in this plan.

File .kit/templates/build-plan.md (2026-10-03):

---
doc_id: PRJ-BLD-001
title: Project prototype build plan
project: Project name
doc_type: Build plan
version: "0.1"
status: Draft
date: YYYY-MM-DD
author: Amish Chadha
license: CERN-OHL-S-2.0
revisions:
  - version: "0.1"
    date: YYYY-MM-DD
    author: Amish Chadha
    change: First build plan; design made constructable
---

# Project prototype build plan

**Plan, not yet built.** How to build the first proof-of-concept prototype, component by component. Building and testing to it is TRL 4 work. Decisions still to be made are kept in the design decisions register (`docs/06-design-decisions.md`), not here.

## 1. What you are building

Every component, pulled apart and numbered in build order

One short paragraph: what the prototype is, how many components, which are made and which are bought, and the main ways they are made.

## 2. What changed to make it buildable

| Component | The concept had | The buildable design has | Why |
| --- | --- | --- | --- |

## 3. Making the components

### 3.1 Component name

Making sketch

**What it is and what it is made from.**

**How to make it.**

1. Mark out ...
2. Cut ...

**How it fits the parts next to it.**

Close-up of the joint

**Check before moving on.**

## 4. Putting it together

### Step 1: ...

Step 1

## 5. First checks

| Check | Requirement | How | Pass when |
| --- | --- | --- | --- |

## 6. Safety stops

## 7. Tools, skills and workspace

## 8. Where the numbers come from

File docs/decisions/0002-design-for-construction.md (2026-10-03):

---
doc_id: SLH-DDR-002
title: SiltHaul design for construction
project: SiltHaul
doc_type: Design decision record
version: "0.1"
status: Draft
date: '2026-10-03'
author: Amish Chadha
license: CERN-OHL-S-2.0
revisions:
- version: "0.1"
  date: '2026-10-03'
  author: Amish Chadha
  change: Constructability review and changes that make the design buildable, decided under Amish's pre-approval of 2026-10-03
---

# 0002: Design for construction

- **Date:** 2026-10-03
- **Status:** accepted

## Context

STANDARDS section 18 asks for every part to be makeable by its stated process and to fit and fasten to its neighbours (Amish, 2026-09-30: "fix the design assumptions to match and be physically feasible"). The TRL 2 concept (SLH-PRC-001 v0.2, SLH-DDR-001) was reviewed part by part in `cad/src/model.py`: how each part is made, how it joins each neighbour, and build123d checks for overlapping parts and for parts that do not touch what holds them. The checks now report no overlaps and no floating parts. Amish pre-approved every recommendation on 2026-10-03: "start with the first 14 repos from the list of 29 projects. I pre-approve the batch runs along with any recommendations you come up with. I also accept any cost overruns or variations from the assumed scope cost." No change alters what SiltHaul does or its pitch; the safety-related changes all take the conservative side.

## Options considered

For each problem the simplest physically sound fix was chosen; the alternatives are noted in Table 1.

## Decision

*Table 1. Changes made for construction.*

| # | Part | Problem found | Change | Why |
| --- | --- | --- | --- | --- |
| 1 | Capstan frame | Over 25 kg in 40 x 40 x 3 tube with solid braces | 40 x 40 x 2 tube throughout, 8 mm bearing plates: 24.7 kg | R9 |
| 2 | Capstan frame | Sling eye at ground level let the capstan tip forward at the overload limit | Anchor bar 40 x 40 x 3 between the rear braces with an eye 200 mm up, level with the drum axis | The pulls line up; the frame is held back by 315 N m |
| 3 | Bearing pads | A 60 mm pad clashed with the first ratchet wheel | Pads 50 mm wide, 180 long | Clearance |
| 4 | Drum | Drum with its bearings was 26 kg, over R9 | 4 mm rings and end discs with six lightening holes; 6 mm ratchet wheels: 23.1 kg with bearings | R9 |
| 5 | Ratchet and pawls | Both pawls on one pivot could not each clear the tooth behind the one they hold | Wheel 1 and its pawl mirrored to the front, on a bracket on the front brace; wheel 2 and its pawl on the post | Each pawl's body clears the teeth; nose 1.3 mm off the face |
| 6 | Chain drive | Sprocket hub inside the chain line; guard wall in the chain's plane | Hub 36 mm; guard moved out to 44 to 70 mm beyond the bearing plane; cranks moved out to suit | Clearance |
| 7 | Shear pin | Not detailed | 4 mm S235 pin through a hub that turns freely on the crank shaft and the shaft itself | R11 |
| 8 | Stakes | Stakes hung free in their tubes | A 32 mm head welded on rests on the stake tube | Each part rests on what holds it |
| 9 | Tail block | One large sheave would have been 300 mm; 20 mm pins at 270 MPa at the limit | Two 125 mm sheaves 175 mm apart on 25 mm pins (138 MPa), spacers, a keeper bar and four anchors | Bought sheaves; strength |
| 10 | Scraper box | Return leg could not pass the box in a 0.7 m door | Box 450 mm wide; return leg 300 mm off the box line | R4 |
| 11 | Scraper box | Vertical back would bulldoze mud on the return | Back slopes 80 mm; skids cut at 45 degrees at the rear | Rides over mud |
| 12 | Bridles | Shackle and lug geometry not defined | 19 mm lug holes, shackle pins through them, chain legs to pear rings 300 mm out | Fixings |
| 13 | Ramp | Deck sheets were drawn self-intersecting and floated between the cheeks | Folded 3 mm trays the full inner width, flanges bolted through the cheeks; roller 10 mm proud of the deck ends | Fixings |

## Consequences

- `cad/src/model.py` holds the constructable design; STEP and STL, SLH-DWG-001 and 002 (Rev P2), the concept media and the build plan pictures are regenerated from it.
- SLH-CAL-001 is rerun on it; costs rise to USD 887.50, still USD 1,112.50 under the value-engineering target.
- `design_state: constructable` is set in `project.yaml`.

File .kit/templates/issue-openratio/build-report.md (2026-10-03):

---
name: Build report
about: Tell us what happened when you built, printed or tested part of this design
title: "Build report: "
labels: build-report
---

This is a research and educational prototype, not a medical device. It is a TRL 3 concept and is not released for fabrication. If you build any part of it, you do so at your own risk. Reports help everyone.

**What you built** (part, sub-assembly or test)

**Materials, tools and settings**

**What worked**

**What did not work, with photos or measurements if you have them**

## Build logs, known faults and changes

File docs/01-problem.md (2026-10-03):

---
doc_id: SLH-PRB-001
title: SiltHaul problem statement
project: SiltHaul
doc_type: Problem statement
version: "0.2"
status: Draft
date: '2026-10-03'
author: Amish Chadha
license: CERN-OHL-S-2.0
revisions:
- version: "0.1"
  date: '2026-09-30'
  author: Amish Chadha
  change: Initial scaffold
- version: "0.2"
  date: '2026-10-03'
  author: Amish Chadha
  change: TRL 2 update; first co-design candidate named (SLH-DDR-001); questions for the first trials
---

# SiltHaul problem statement

Flood mud is heavy, wet and contaminated, and it sits in the places hardest to reach with machines: ground-floor rooms, narrow lanes and drains. Clearing it is left to people with shovels and buckets.

## The problem

Mud has to be dug, lifted, carried out and dumped, often through a single door. OSHA lists back, knee and shoulder injuries from manual lifting among the main risks for flood clean-up workers and recommends teams for heavy items ([OSHA](https://www.osha.gov/flood/response)). The longer people spend in the mud, the longer they are exposed to contaminated water; after the Kerala floods, officials linked leptospirosis risk to contact with water contaminated by animal urine and urged clean-up volunteers to take preventive medicine ([Mongabay, 2018](https://india.mongabay.com/2018/09/leptospirosis-outbreak-causes-concern-in-kerala-after-the-floods/)).

Mechanical options exist but do not fit. Mines use powered double-drum scraper hoists, or slushers, that drag a scraper box on a pull rope and return it on a tail rope ([Mining History Association](https://www.mininghistoryassociation.org/Journal/MHJ-v22-2015-Reynolds.pdf)); a recent Sulzer design uses electric motors inside the drums and has ceased without grant ([WO2017216731A1](https://patents.google.com/patent/WO2017216731A1/en)). These are heavy, powered and built for mine drives. Excavators and loaders cannot enter homes or narrow lanes. There is no portable, hand-powered slusher for flood recovery.

## Users and context

| User | Need | Context |
| --- | --- | --- |
| Householders and volunteers | Get mud out of rooms faster and with less lifting and less time in the mud | Ground floors of homes, shops and places of worship after a flood |
| Relief NGOs and community groups | A kit that is cheap, portable, needs no fuel and can be used by untrained volunteers after a short briefing | Many sites, poor road access, limited power |
| Municipal drain and sanitation crews | Clear silted drains and lanes where machines cannot reach | Narrow streets, open drains, culverts |
| Local fabricators | Drawings using stock steel, rope and pulleys | Workshops near flood-prone areas |

## Operating environment

- Wet silt and mud of varying depth, from a thin layer to deep deposits; mixed with debris, rubbish and sometimes sewage.
- Ground-floor rooms with doorways about 0.7 to 0.9 m (28 to 35 in) wide (estimate), steps and thresholds.
- Lanes and open drains in dense neighbourhoods.
- Walls that may be weakened and wet after the flood.
- Hot, humid conditions, or cold and wet in temperate regions; no power.

## Constraints

- Prototype parts budget: USD 2,000 or less.
- Hand powered only.
- Fits through a standard doorway and into a car or small pickup.
- Anchors must not rely on flood-damaged walls; the tail sheave needs its own anchoring option.
- Buildable with hand tools and a small welder from stock steel, rope and commercial pulleys.
- Open design: hardware under CERN-OHL-S-2.0, any calculators under MIT.

## Out of scope

- Pumping standing water.
- Removing large debris such as furniture, vehicles or fallen structures.
- Motorised versions.
- Disposal and treatment of the removed mud.

## Prior work

| Prior work | What it does | Gap for these users | Source |
| --- | --- | --- | --- |
| Mine slusher (tugger-scraper) | Powered two-drum hoist drags a scraper along a mine floor and returns it by tail rope through a sheave | Compressed-air or electric, heavy, built for mines | [link](https://www.mininghistoryassociation.org/Journal/MHJ-v22-2015-Reynolds.pdf) |
| US2588657A, slusher bucket (expired) | Scraper bucket worked by lead, return and tail ropes on a portable hoist | Mining equipment for a powered hoist | [link](https://patents.google.com/patent/US2588657A/en) |
| US3532170A, slusher scraper bucket and blade assembly (expired) | Scraper bucket and blade design for slushers | Mining equipment for a powered hoist | [link](https://patents.google.com/patent/US3532170A/en) |
| WO2017216731A1, scraper winch (Sulzer, ceased) | Double-drum scraper winch with electric motors inside the drums and remote control | Powered mine winch; no hand operation | [link](https://patents.google.com/patent/WO2017216731A1/en) |

## Co-design

A disaster relief NGO, a municipal disaster management unit or a volunteer fire service with regular flood clean-up experience, who can supply realistic mud and building conditions and test the kit with volunteers. First candidate to approach (not agreed): the Kerala State Disaster Management Authority and its civil defence volunteers, since Kerala's 2018 clean-up is the case that sparked the idea (SLH-DDR-001).

## Safety

> **Safety:** Any tool that moves mud by rope puts volunteers near ropes and anchors under tension, in buildings that may be damaged and in mud that may carry sewage and disease. The design answers are in SLH-PRC-001, Safety; the clean-up hazards themselves (structure, electricity, contamination) stay with the users and local health advice.

## Questions for the first trials

These are settled by trials (TRL 4), not by design decisions:

- How well does the box fill and drag in different muds, from liquid slurry to stiff clay?
- How often is the floor slab sound enough for the tail block's drilled anchors (the only tail anchor used, SLH-DDR-001)?
- Can one capstan serve several rooms in turn without re-anchoring outside?
- How does the rope get past steps and turns in the building? The doorway ramp covers thresholds up to 110 mm; turns are out of scope for the prototype.
- Is a smaller drain version, pulled along an open channel, worth a separate variant?

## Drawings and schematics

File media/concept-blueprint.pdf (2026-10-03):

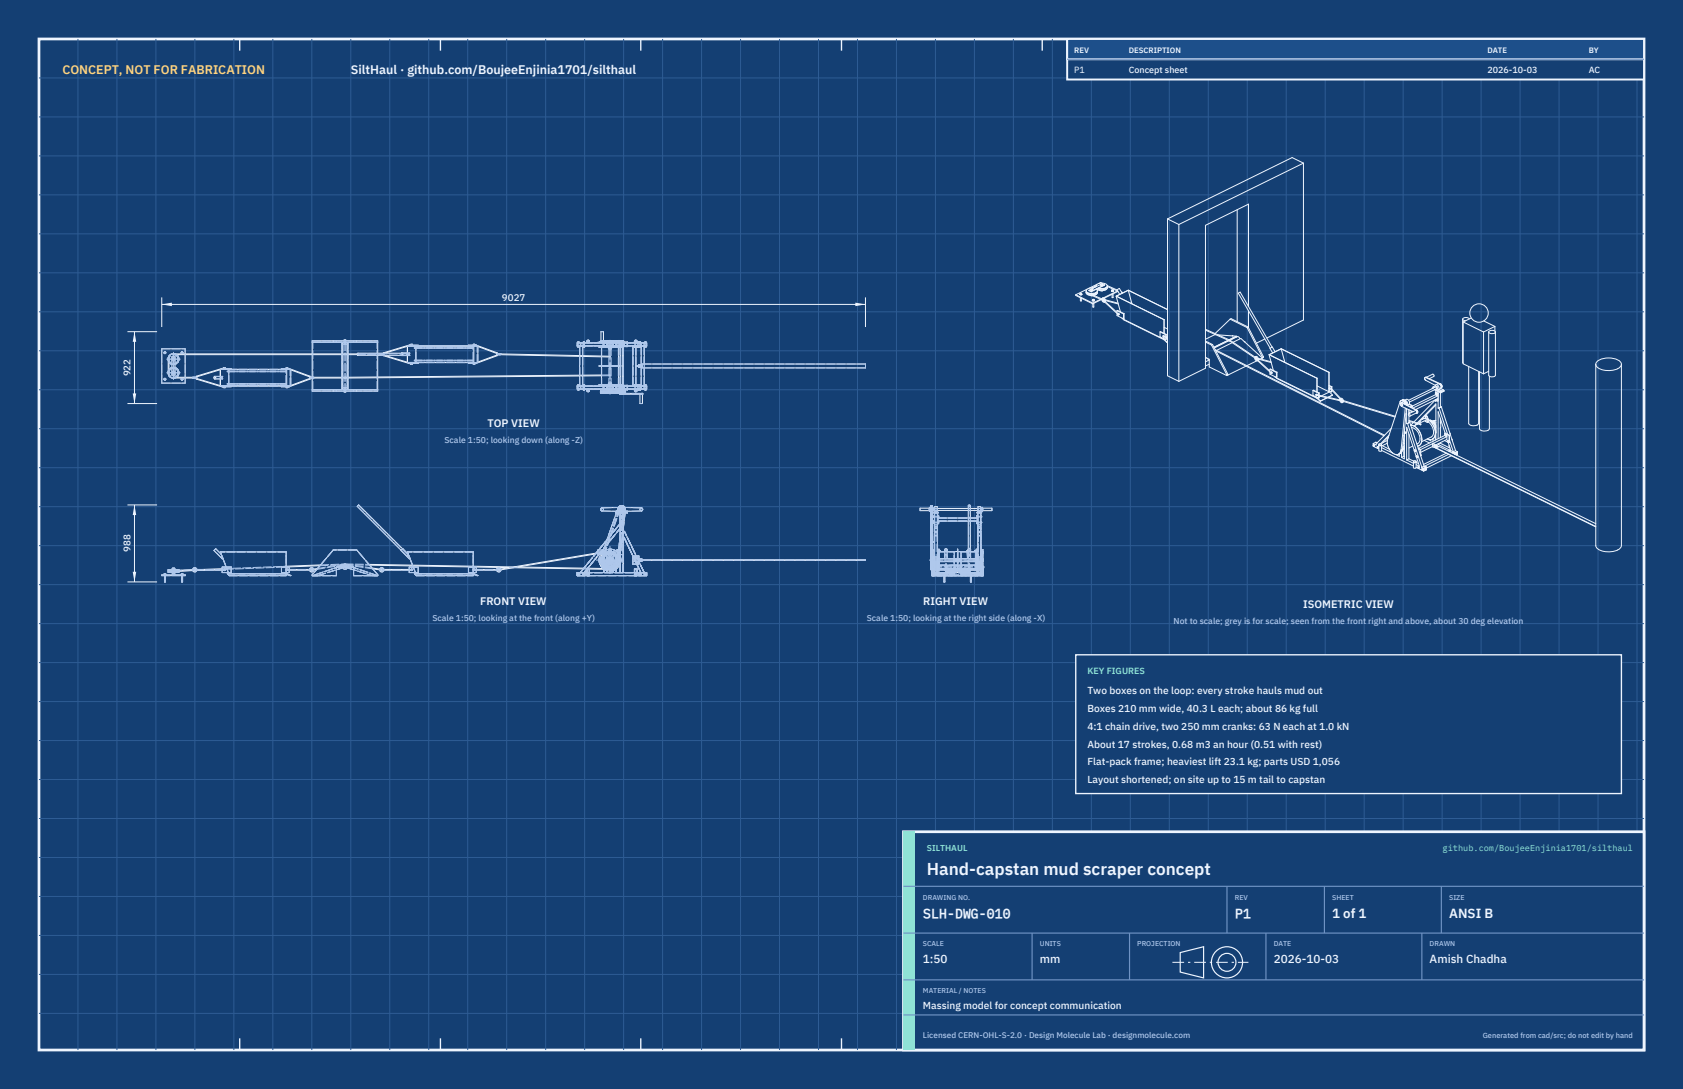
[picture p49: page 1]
CONCEPT, NOT FOR FABRICATION; SiltHaul · github.com/BoujeeEnjinia1701/silthaul; FRONT VIEW; TOP VIEW; RIGHT VIEW; ISOMETRIC VIEW; REV; DESCRIPTION; DATE; Concept sheet; SILTHAUL; github.com/BoujeeEnjinia1701/silthaul; DRAWING NO. SLH-DWG-010; REV P1; SHEET 1 of 1; SIZE ANSI B; SCALE 1:50; UNITS mm; PROJECTION; DRAWN Amish Chadha; Licensed CERN-OHL-S-2.0 · Design Molecule Lab · designmolecule.com; Generated from cad/src; do not edit by hand

Scale 1:50; looking down (along -Z)

Scale 1:50; looking at the front (along +Y)

Scale 1:50; looking at the right side (along -X)

Not to scale; grey is for scale; seen from the front right and above, about 30 deg elevation

KEY FIGURES
Two boxes on the loop: every stroke hauls mud out
Boxes 210 mm wide, 40.3 L each; about 86 kg full
4:1 chain drive, two 250 mm cranks: 63 N each at 1.0 kN
About 17 strokes, 0.68 m3 an hour (0.51 with rest)
Flat-pack frame; heaviest lift 23.1 kg; parts USD 1,056
Layout shortened; on site up to 15 m tail to capstan

Hand-capstan mud scraper concept

MATERIAL / NOTES
Massing model for concept communication

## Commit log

2026-10-03 SiltHaul at TRL 3: constructable design (kit 1.7.0)
    Problem, concept and requirements; sizing calculations; CAD model, STEP and STL; general arrangement drawing; bill of materials; build plan with making sketches, joint close-ups and step pictures; design decisions register (all decided under Amish's 2026-10-03 pre-approval); TRL 2 and TRL 3 review; photoreal renders and storefront card. Private until Amish opens it.
    [bom.csv, results.csv, silthaul-assembly.step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]
2026-10-03 Carry Amish's 2026-10-03 requirement decisions into the design
    Amish chose option A on each requirement decision ("1A 2A 3A 4A 5A 6A 7A 8A 9A 10A 11A"). CampBreak: primed foot valve, pre-coupled suction hose and a drilled 30 s gather (R9 now 3.2 min at 100 m, me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
    [bom.csv, results.csv, silthaul-assembly.step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]
2026-10-04 Carry Amish's round-2 and round-3 decisions into the design
    Amish approved all 46 round-2 recommendations ("i agree with all the 46 recommendations you provided. please proceed.") and all round-3 recommendations ("For round 3, I agree with all your proposed r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
2026-11-05 Kit 1.9.1 upgrade: pipeline documents and detailed CAD for every option
    STEM check with fixes under the standing instruction and an independent
    review, concept options scored against the user requirements, URS, PRS,
    RTM, REG, FEA, RSK, MKT, PLN and DDR, every option modelled at D3 with
    cad/fidelity.json passing, and the concept options picture rendered with
    Blender Cycles on Amish's Mac. Concept choices stay proposed, awaiting
    Amish.
    Claude-Session: https://claude.ai/code/session_01LppsZSzPTJWTBAV5wh1Goq

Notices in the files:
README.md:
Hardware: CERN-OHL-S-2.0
